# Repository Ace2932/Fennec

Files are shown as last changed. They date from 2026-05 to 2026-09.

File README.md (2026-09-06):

# Fennec — Autonomous Quadruped

> **Fennec** is an autonomous quadruped I'm building on the [NovaSM3](https://github.com/cguweb-com/Arduino-Projects/tree/main/Nova-SM3) platform (by Chris Locke / [novaspotmicro.com](https://novaspotmicro.com/)) — rebuilt around a unified Feetech STS3215 TTL servo bus, NVIDIA Jetson Orin Nano Super compute, and ROS 2 Humble, as a platform for Vision-Language-Action (VLA) model deployment, 3D SLAM, and autonomous mobile manipulation.

**Status:** 🔧 Phase 1 — hardware bring-up + sim training. **Both PCBs ordered 2026-07-01 (JLCPCB)** — power board v2 (Pattern B bus master, INA226 rail telemetry, Phase-4 arm rail provisioned) + logic board. Firmware critical-path green (safety FSM, watchdogs, servo limits, joint-map loader; rostest suites in CI). Legs (**leg_v6**) printing; chassis-integration + CAD fit-gate audits closed; measured leg geometry → URDF + IK green. **🎉 RL locomotion walks in sim** (MuJoCo MJX + Brax PPO, 2026-07-16) — stair-climb curriculum in progress. **See [`STATUS.md`](./STATUS.md) for the live blockers / next-actions board.**
**Platform:** Quadruped (12 DOF) — arm (6-DOF, Phase 4 future) on shelf
**Compute:** NVIDIA Jetson Orin Nano Super 8GB
**Middleware:** ROS 2 Humble
**Last updated:** July 22, 2026

---

> **Design outline:** [`docs/design-outline.md`](./docs/design-outline.md) — the canonical top-level design document (architecture, doctrines, lane status). Start there.

## Table of Contents

1. [Project Overview](#project-overview)
2. [Differences from Stock NovaSM3](#differences-from-stock-novasm3)
3. [Hardware Architecture](#hardware-architecture)
4. [Software Architecture](#software-architecture)
5. [Power System](#power-system)
6. [Network Topology](#network-topology)
7. [Bill of Materials](#bill-of-materials)
8. [Build Roadmap](#build-roadmap)
9. [Pre-Assembly Test Sequence](#pre-assembly-test-sequence)
10. [Setup Guide](#setup-guide)
11. [Open Decisions](#open-decisions)
12. [References & Credits](#references--credits)

---

## Project Overview

This project is a heavily modified fork of the open-source NovaSM3 quadruped, redesigned to serve as a research platform for embodied AI. Stock Nova uses PWM hobby servos and a Raspberry Pi running custom locomotion code. This build replaces:

- **12 servos** with Feetech STS3215 TTL bus servos for unified protocol, real-time joint feedback (position, load, temperature, voltage), and elimination of PWM wiring complexity. Six additional STS3215 (arm) remain on shelf for Phase 4.
- **The Pi** with an NVIDIA Jetson Orin Nano Super (67 TOPS sparse INT8 / ~33 TOPS dense; 8GB RAM tight but workable for VLA inference + ROS 2 + SLAM — see Phase 4 notes). Real-time servo bus is offloaded to a Teensy 4.1 (Pattern B); Jetson runs ROS 2 + perception only.
- **The stock perception** with Intel RealSense D456 (depth + RGB + IMU) and Unitree L2 4D LiDAR (360° × 96° FOV, 30m range)
- **The stock locomotion stack** with ROS 2 Humble (Jetson) + Teensy bus master (Pattern B) + Nav2 + RTAB-Map / POINT-LIO

The arm is carried over from a prior SO-ARM101 build, also Feetech-based. **v1 build scope: quadruped only (12 servos active).** Arm install + integration is Phase 4 future work — bus IDs 13-18 and the 7.5V arm-rail buck footprint (D42V55F7) are reserved on the PCB v6 redesign so the future install is a populate-and-go.

### Goals

- ✅ Unified TTL servo bus across locomotion (12 servos v1; future-ready for 18 with arm)
- 🔧 ROS 2 locomotion via micro-ROS bridge to Teensy 4.1 (Teensy owns the Feetech bus in Pattern B; FE-URT-1 retained as bench fallback)
- 🔧 RL locomotion policy trained in simulation (`sim/nova_mjx`, MuJoCo MJX + Brax PPO) — ✅ walks in sim (2026-07-16); terrain curriculum + stair climbing + sim2real transfer in progress
- 📋 3D SLAM using LiDAR + visual-inertial fusion (POINT-LIO baseline, RTAB-Map comparison)
- 📋 Autonomous navigation (Nav2) on legged platform with stair climbing
- 📋 VLA fine-tuning and deployment for mobile manipulation tasks
- 📋 Open-source documentation of every design decision for community reuse

---

## Differences from Stock NovaSM3

| Subsystem | Stock NovaSM3 | This Build |
|---|---|---|
| Compute (main) | Raspberry Pi 4 | NVIDIA Jetson Orin Nano Super 8GB |
| Compute (MCU) | Teensy 4.0 | Teensy 4.1 (more RAM + SD slot) |
| Aux MCU | Arduino Nano | Arduino Nano (kept, peripherals only) |
| Locomotion servos | 12× PWM hobby servos | 12× Feetech STS3215 (4× 12V/30kg hip, 8× 7.4V/19kg femur/tibia) |
| Arm | None (stock) | 6× Feetech STS3215 from SO-ARM101 — **on shelf, Phase 4** |
| Servo protocol | PWM (one signal per servo) | TTL half-duplex serial bus (daisy-chained) |
| Perception | None / optional | RealSense D456 + Unitree L2 LiDAR |
| Middleware | Custom Arduino loops | ROS 2 Humble + micro-ROS |
| Power | 3S 11.1V LiPo | 4S 14.8V LiPo + Pololu buck rails (7.5V leg / 12V hip / 12V L2 dedicated / 12V Jetson / 5V aux). XL4016 dropped after capacity audit. |
| Print materials | PLA / PETG | PA6-CF (structural) / PETG-CF (secondary) / TPU 95A (foot pads + strain relief) |
| Print feed | Direct from spool | **Creality SpacePi X4 dryer → 4 mm PTFE Bowden → P1S** (AMS HF bypassed for PA6-CF — re-absorbs moisture in AMS chamber, defeats pre-drying) |

### Why redesign the PCB (v5.2b → v6)

After the v3.2 architecture audit, the stock Nova PCB v5.2b can't host the upgraded power tree (Pololu modules, INA226 telemetry, hard-cutoff MOSFET, E-stop chain) or the Pattern A/B bus master selector. The redesign retains the spirit of the stock board (Arduino Nano aux slot, battery input geometry) and adds the new safety + power architecture. Full feature set in [`hardware/pcb-mods/README.md`](./hardware/pcb-mods/README.md).

### What carries over from Nova v5.2b

- Arduino Nano slot for aux peripherals — **v3.5 cut**: OLED + WS2812B only (PIR / ultrasonic / MP3 / MPU-6050 removed; D456 + L2 perception stack covers their roles)
- Battery input + reverse polarity protection geometry (replicated with MOSFET-based reverse protection instead of diode)
- Power switch, voltmeter, fuse (MRBF-30 in Blue Sea 5191 block, OFF-board at pack — ~9 kA AIC @ 16.8 V clears this pack's ~1.5–3 kA dead-short with 3–4× margin; ANL's 6 kA rejected, Class T superseded 2026-06-12)

### What changes

- All 12 PWM servo output headers removed (Feetech bus is daisy-chain TTL, doesn't use PWM)
- XL4016 buck footprints → Pololu D42V110-class module footprints
- Add: SN74LVC125A half-duplex driver (Pattern B prep), INA226 ×3, E-stop chain, hard-cutoff MOSFET, **MRBF-30 fuse OFF-board** (Blue Sea 5191 at pack — F1 not on PCB), bulk caps at injection points, bus-integrity footprints (series R + ferrite beads), reserved arm-rail buck footprint

---

## Hardware Architecture

### Block diagram

```
┌────────────────────────────────────────────────────────────────────┐
│                  NVIDIA Jetson Orin Nano Super 8GB                 │
│                          (ROS 2 Humble)                            │
│   • Nav2, SLAM, VLA inference, sensor fusion                       │
│   • Sends /joint_commands to Teensy via micro-ROS over USB         │
│   • Built-in WiFi 5 (802.11ac/ab/gn) per NVIDIA P3766 spec sheet   │
└──┬──────────┬─────────────┬─────────────┬───────────────────────────┘
   │ USB-C    │ USB 3.1     │ Ethernet    │ USB (micro-ROS transport)
   │          │             │             │
┌──▼───────┐ ┌▼───────────┐ ┌▼───────────┐ ┌▼─────────────────────────┐
│ Realsense│ │ FE-URT-1   │ │ Gig switch │ │ Teensy 4.1 (BUS MASTER v1)│
│ D456     │ │ (debug/    │ │            │ │  • Real-time gait loop    │
│ (depth + │ │  bench     │ │ ◄─ L2 ─►   │ │  • UART → SN74LVC125A → bus   │
│  RGB +   │ │  fallback) │ │            │ │  • INA226 I²C reader      │
│  IMU)    │ │            │ └────────────┘ │  • E-stop GPIO sense      │
└──────────┘ └────┬───────┘                │  • micro-ROS over USB     │
                  ↓                        └──┬────────────────────────┘
              (JP_BUS_MASTER                  │ UART → SN74LVC125A half-duplex
               solder bridge:                 │ (active v1 path)
               default = B,                   │
               flip to A for ID setup)        ▼
                                  ┌───────────────────────┐
                                  │ 12× STS3215 (TTL bus) │
                                  │ per-leg: FL1-3 FR4-6  │
                                  │ RL7-9 RR10-12 (h/f/t) │
                                  │  IDs 13-18: ⏸ arm    │
                                  │  (Phase 4 reserved)   │
                                  └───────────────────────┘

       ┌──── Arduino Nano (USB-serial bridge from Jetson:
       │                   OLED + WS2812B status LEDs) ────┐
       │                                                                  │
       └──────────────────────────────────────────────────────────────────┘
```

### Servo configuration

| Joint group | Count | Servo | Voltage | Bus IDs | Status |
|---|---|---|---|---|---|
| Hips | 4 | STS3215 30kg | 12V | 1-4 | v1 active |
| Femur + tibia | 8 | STS3215 19kg | 7.4V | 5-12 | v1 active |
| Arm (shoulder + elbow) | 3 | STS3215 19kg | 7.4V | 13-15 | ⏸ Phase 4 — reserved |
| Arm (wrist + gripper) | 3 | STS3215 19kg | 7.4V | 16-18 | ⏸ Phase 4 — reserved |

**v1 build = 12 active servos** on a single daisy-chained TTL bus, 2 active servo-power voltage levels (7.5V leg, 12V hip) plus dedicated 12V/2.6A L2 LiDAR buck and 12V/3A Jetson buck. Bus master is the **Teensy 4.1 (Pattern B)** via a SN74LVC125A half-duplex driver. Bus IDs 13-18 and the 7.4V arm rail (D42V55F7 footprint) reserved on PCB v6 for Phase 4 arm install — populate-and-go.

### Bus master pattern

**Pattern B is v1 default.** Both paths live on PCB v6 via solder bridge `JP_BUS_MASTER`.

- **Pattern B (v1 active):** Teensy 4.1 hardware UART → SN74LVC125A quad tri-state buffer (half-duplex driver) → TTL bus pads. Bare-metal real-time loop at 200-500 Hz. Jetson sends joint targets via micro-ROS over USB; Teensy translates to bus reads/writes. Survives Jetson restarts, kernel preemption, CUDA stalls, journald flushes — none of which affect bus servicing. Solder bridge defaults to B.
- **Pattern A (bench / debug fallback):** Jetson → USB → FE-URT-1 → TTL bus. Use for: initial servo ID assignment with the Feetech FD / SCServo SDK Python tools from a workstation (simpler than booting micro-ROS for ID setup), debug if Teensy firmware misbehaves, post-mortem inspection of bus traffic. Flip `JP_BUS_MASTER` to A.

**Why B as default (decision history):** Linux is not a real-time OS. USB-CDC latency on Jetson runs 1-10 ms typical, 50 ms+ under load. **What Pattern B actually buys:** bus-servicing isolation on the Teensy side — UART transactions to all 12 servos complete on time even when Jetson is jittery, so the bus doesn't time out and servos don't fault. The gait controller still runs on Jetson and publishes targets at 100 Hz, so Jetson's command rate is still Linux-bounded; the Teensy oversamples at 200-500 Hz against the last received target, holding it through Jetson stalls. A 100 ms Linux freeze becomes "robot pauses mid-step," not "bus dies and robot falls." v3.2 originally defaulted to A with "migrate if measurement forces it" — v3.3 flips to B-default because the migration cost is just populating one $1 IC + Phase 1 firmware work, and skipping the measure-then-migrate path eliminates a Phase 2 surprise. See Open Decisions row 5.

**Phase 1 acceptance gate (revised):** Pattern B's real guarantee is bus-servicing isolation on the Teensy side, not full RTT through Linux. Two mandatory criteria + one sanity check:
1. **Teensy local loop tick jitter p99 <100 µs** over 60 seconds (bare-metal — easy if firmware is right)
2. **`/joint_commands` arrival rate ≥99% of 100 Hz target** over 60 seconds (Jetson + uROS healthy)
3. *(Sanity)* End-to-end RTT median <5 ms, p99 <20 ms — Linux-bounded, not a hard pass/fail

If (1) misses → debug Teensy firmware (DMA vs ISR, UART config). If (2) misses → debug Jetson uROS / USB cable / CPU contention. If only (3) is high → accept: Teensy holds last command under Jetson jitter, robot stays stable.

---

## Software Architecture

### ROS 2 stack (target)

```
┌──────────────────────────────────────────────┐
│             Application Layer                │
│  • Behavior tree / mission FSM               │
│  • VLA policy node                           │
│  • Teleop bridge                             │
└──────────────────────────────────────────────┘
┌──────────────────────────────────────────────┐
│            Navigation Layer                  │
│  • Nav2 (planning + control)                 │
│  • robot_localization (EKF)                  │
└──────────────────────────────────────────────┘
┌──────────────────────────────────────────────┐
│              Perception Layer                │
│  • RTAB-Map / POINT-LIO (3D SLAM)            │
│  • realsense2_camera                         │
│  • unitree_lidar_ros2                        │
└──────────────────────────────────────────────┘
┌──────────────────────────────────────────────┐
│            Locomotion Layer (Jetson)         │
│  • Gait controller (8-phase walk)            │
│  • 3-DOF-per-leg IK solver                   │
│  • Publishes /joint_commands                 │
│  • Subscribes /joint_states                  │
└──────────────────────────────────────────────┘
┌──────────────────────────────────────────────┐
│        Bus Master Layer (Teensy 4.1)         │
│  • micro-ROS client (USB transport)          │
│  • SCServo SDK port — Feetech bus driver     │
│  • SN74LVC125A half-duplex TX/RX gating          │
│  • Real-time loop @ 200-500 Hz               │
│  • INA226 I²C reader → /diagnostics          │
└──────────────────────────────────────────────┘
┌──────────────────────────────────────────────┐
│              Hardware Layer                  │
│  • Feetech STS3215 bus (12 servos v1)        │
│  • IMU driver, aux peripheral I/O            │
└──────────────────────────────────────────────┘
```

### Key software components

| Component | Purpose | Status |
|---|---|---|
| ROS 2 Humble | Middleware | 📋 Install on Jetson |
| `librealsense2` | RealSense SDK | 📋 ARM64 build |
| `realsense2_camera` | ROS 2 wrapper for D456 | 📋 apt install |
| `unilidar_sdk2` | Unitree L2 SDK | ✅ Built green on Jetson (official `unitreerobotics/unilidar_sdk2`, **not discodyer fork** — official now bundles ROS 2 wrapper) |
| `unitree_lidar_ros2` | ROS 2 wrapper for L2 | ✅ Built + streaming. Use **Ace2932/unilidar_sdk2 `fix/imu-bridge-double-call` branch** — fixes upstream IMU bridge bug where `getImuData()` is called twice in `timer_callback()`, draining the SDK queue before publish. |
| POINT-LIO | LiDAR-inertial SLAM | 📋 Eval first |
| RTAB-Map | Visual-LiDAR SLAM | 📋 Compare with POINT-LIO |
| Nav2 | Autonomous navigation | 📋 Phase 3 |
| robot_localization | EKF sensor fusion | 📋 Phase 2 |
| micro-ROS (Teensy) | Embedded ROS 2 | 📋 Phase 2 |
| SCServo SDK (Teensy port) | Feetech bus driver running on Teensy in Pattern B | ⚠️ Already familiar from SO-ARM101 — port to TeensyDuino in Phase 1 |
| MJX/Brax sim (`sim/nova_mjx`) | RL locomotion training — MuJoCo MJX physics, Brax PPO, procedural terrain curriculum (rough / steps / stairs), domain randomization | 🔧 Walks in sim (flat trot, 2026-07-16); stair-climb curriculum active |

---

## Power System

### Voltage rails

```
4S LiPo 14.8V nominal (12.8-16.8V)
   │  MRBF-30 fuse (off-board) · MOSFET reverse-protection · MOSFET hard-cutoff @12.4V · E-stop NC (servo rails only)
   │
   ├── Pololu D42V110F7  ──► 7.5V/10A ──► 8× STS3215 19kg femur/tibia
   │       (star injection at 4 points along chain, bulk caps near point of load)
   │
   ├── Pololu D42V110F12 ──► 12V/9A   ──► 4× STS3215 30kg hips ONLY
   │
   ├── Pololu D24V22F12  ──► 12V/2.6A ──► Unitree L2 LiDAR (1A, LC filter on output)
   │
   ├── Pololu D42V55F12  ──► 12V/~3A  ──► Jetson Orin Nano (barrel jack)
   │
   ├── [reserved D42V55F7] ► 7.5V/3-8A ──► 6× STS3215 arm (Phase 4 — footprint unstuffed)
   │
   └── UBEC 5V/5A ──► 5V rail ──► fans, aux 5V peripherals

   INA226 ×3 (leg 7.5V, hip 12V, Jetson 12V) ──► I²C ──► Teensy 4.1 ──► ROS 2 diagnostics
   13.0V comparator ──► Teensy GPIO ──► /battery_low ──► Jetson clean shutdown
   12.4V comparator ──► MOSFET ──► breaks battery feed (autonomous backstop)
```

### Notes

- All rails share a common ground
- Jetson MAXN peak power ~25W → 2.1A at 12V, plus USB peripherals (D456 streaming ~2-3W, FE-URT-1 ~0.5W) → **~2.5A continuous worst case**. **Pololu D42V55F12** derates to ~3A continuous at 14.8V Vin (4.5A typ headline is at 42V Vin) → **~1.2× headroom**. Modest, not generous; watch thermal under sustained VLA inference + RealSense stream + Nav2 planning. Min Vin 12V — set LiPo LVC alarm at 3.3V/cell = 13.2V to stay above dropout.
- **Leg rail D42V110F7** (10A typ @ 42V Vin, derates at 14.8V Vin) sized for walking-gait avg 5-8A with bulk caps absorbing 25-40A impact transients near each star injection point. See [`docs/power-budget.md`](./docs/power-budget.md).
- **Hip rail D42V110F12** (9A typ @ 42V Vin) sized for 4× 30kg hips only — sustained avg ~8A. L2 LiDAR was moved off this rail to a dedicated D24V22F12 buck (v3.4) because combined hip+L2 load was margin-thin under 14.8V Vin derating.
- **L2 LiDAR rail D24V22F12** (2.6A / 12V / 36V Vin max) — dedicated buck for the LiDAR's 1A draw with LC filter on output. Clean power, no servo transient ringing.
- **Battery low-voltage chain** (ordered by trip point):
  1. **13.2V** — 608AC charger LVC alarm beeps (user-facing warning)
  2. **13.0V** — graceful-shutdown comparator → Teensy `/battery_low` topic → Jetson `systemctl poweroff` (clean SD unmount). ~30-60s window before hard cutoff.
  3. **12.4V** — autonomous MOSFET hard-cutoff on battery feed (drops everything; Jetson should already be shut down per #2)
- **E-stop** kills leg + hip + L2 rail enables (LiDAR stops spinning) — Jetson rail stays alive for post-mortem debug + telemetry capture.
- L2 self-heats below 30°C ambient; ~30-60s delay before point cloud output on cold boots
- LC filter sits on the D24V22F12 output to clean any switching ripple before the L2 input (UDP packet loss is the failure mode)

### Battery safety

- Always charge inside a LiPo safe bag
- Two 4S packs alternated; storage-charge to 3.8V/cell if unused >1 week
- Label packs (A/B) with first-use date; track cycle counts

---

## Network Topology

Point-to-point — no switch on the robot (decision 2026-08-14).

```
┌──────────────────────────┐               ┌────────────────────────┐
│ Unitree L2 LiDAR         │     Cat 6      │ Jetson Orin Nano       │
│ Static IP: 192.168.1.62  ├────────────────┤ eth0: 192.168.1.2/24   │
│ UDP target port: 6101    │    (direct)    │ wlan0: DHCP from home  │
└──────────────────────────┘                └────────────────────────┘
```

- L2 → UDP port 6101 on the Jetson, direct on `eth0`
- Jetson's `eth0` needs a manual static IP because L2 is not a DHCP client/server
- WiFi (built-in WiFi 5 / 802.11ac module on P3766 kit) handles dev SSH access + internet, leaving Ethernet free for the LiDAR. BT presence not explicitly listed in spec — verify on arrival.
- The 5-port switch is bench gear only — a dev laptop can join via the switch on the bench when wanted; it is not mounted on the robot.

---

## Bill of Materials

Full BOM lives in [`BOM.md`](./BOM.md). High-level summary:

| Category | Cost |
|---|---|
| Compute + perception | ~$1,300 (NVMe deferred — NAND shortage) |
| Servos | ~$320 active (12-servo v1) + 6 SO-ARM101 carryover on shelf |
| Power + safety | ~$338 (Pololu rails + INA226 + E-stop + MOSFET hard-cutoff + graceful-shutdown comparator) |
| Mechanical + hardware | ~$110 |
| Sensors (stock Nova) | ~$76 |
| Filament + Bambu accessories | ~$700 (− Magigoo via Bambu liquid glue substitution) |
| Wiring + consumables | ~$80 |
| **Realistic total** | **~$2,963** (v3.4: XT60 via Ovonic, Bambu glue, XL4016 ×2 return save $58 total) |

---

## Build Roadmap

**Superseded — this roadmap is the May-2026 plan kept for history. Live state: [`STATUS.md`](STATUS.md) (boards fabbed + populated to stage 9, firmware links, legs printing).**

### Phase 0 — Pre-build setup (current)

3-week sequenced plan in [`docs/work-schedule.md`](./docs/work-schedule.md). Front-loads leg-joint CAD + prints; reserves 2026-05-29 away-week for laptop-only PCB schematic work in KiCad.

- [x] Define modified BOM (v3.4: Pattern B default, Pololu 4-buck split incl. dedicated L2, full safety, arm deferred)
- [x] Validate component compatibility (Jetson power rail, Feetech bus, L2 ethernet)
- [x] Pick LiPo charger → **ISDT 608AC**
- [x] Power rail audit (XL4016 → Pololu D42V110-class)
- [x] Confirm v1 scope = quadruped only (arm → Phase 4)
- [x] Bus master decision → Pattern B (Teensy + 74HC125) v1 default
- [x] Set up GitHub repo with this README and BOM

**Week 1 (2026-05-15 → 2026-05-22):**
- [x] Leg CAD complete — V5 OpenSCAD original-shell-carve (`hardware/cad/leg_v5/`, STS3215 cavity in original NovaSM3 STLs). Pending: caliper on-hand servos + first-article leg-joint print.
- [ ] Install KiCad 8.x + Pololu library on laptop; cache datasheets for offline use during away-week
- [ ] Back up LeRobot Pi SD contents
- [ ] Create NVIDIA Developer account, download JetPack 6.x image

**Week 2 (2026-05-22 → 2026-05-28):** detailed checklist in [`docs/checklists/week-2.md`](./docs/checklists/week-2.md)
- [ ] Carryover from Week 1: caliper pass + first-article leg print (V5 leg CAD itself is done)
- [ ] ROS 2 Humble + librealsense2 + unilidar_sdk2 on Jetson (Jetson already flashed + persistent — Week 1 head-start)
- [ ] PlatformIO + TeensyDuino + micro-ROS Teensy firmware skeleton (compile-green)
- [ ] KiCad install + Pololu library (PCB v6 prep for Week 3)
- [ ] Bambu Studio + PA6-CF drier preheat

**Week 3 — Away (2026-05-29 → 2026-06-05, laptop only):**
- [x] PCB v6 **schematic** captured in KiCad 9 (2026-06-03) — §1-§8 hierarchical, all 54 parts footprinted, pin-name wiring audit passed, ERC-clean (1 intentional warning: reserved arm rail). See [`hardware/pcb-mods/README.md`](./hardware/pcb-mods/README.md)
- [ ] PCB v6 **layout** + DRC + Gerber export in KiCad
- [ ] Backup: continue Teensy firmware / URDF / ROS 2 scaffolding if PCB stalls or finishes early

**Week 4+ (back to shop):**
- [x] ~~Bench-validate prints; submit Gerbers to PCBWay (~$60)~~ — both boards fabbed at JLCPCB 2026-07-01 (~$203 all-in, see STATUS.md); continue Phase 1 hardware bring-up
- [ ] Order remaining parts (switch, Pololu bucks ×4, charger bundle, safety parts, accessories) — NVMe deferred

### Phase 1 — Hardware bring-up (weeks 1-4)

- [ ] Flash JetPack 6.x to microSD; firmware update Jetson if needed
- [ ] Boot Jetson, complete Ubuntu setup
- [ ] Verify pre-installed WiFi works; install AX210NGW only if missing. Confirm BT presence.
- [ ] Install ROS 2 Humble + librealsense2 + unilidar_sdk2 (run from 128GB microSD; NVMe deferred)
- [ ] D456 standalone test (`realsense-viewer`)
- [ ] L2 standalone test (included 12V adapter + rviz2)
- [ ] Print parts: Bambu P1S + PA6-CF (dry 24h before each print)
- [ ] Bench-validate Pololu D42V55F12 / D42V110F7 / D42V110F12 / D24V22F12 / UBEC 5V (per BOM §12 step 2)
- [ ] Verify E-stop chain + MOSFET hard-cutoff @ 12.4V + INA226 I²C reads
- [ ] **Write Teensy firmware** (Pattern B critical path) — micro-ROS client + SCServo SDK port + SN74LVC125A TX/RX gating
- [ ] ID setup pass: flip `JP_BUS_MASTER` to A (FE-URT-1), assign servo IDs **1-12** (v1 active), label each. IDs 13-18 reserved for Phase 4.
- [ ] Flip `JP_BUS_MASTER` back to B (default). Verify Teensy firmware drives single servo, then full 12-servo chain.
- [ ] **Acceptance gate** (two mandatory + one sanity, see "Bus master pattern" section): Teensy tick jitter p99 <100 µs + `/joint_commands` arrival ≥99% of 100 Hz + RTT median <5 ms / p99 <20 ms. Pattern A is not a workaround if (1) or (2) miss.
- [ ] Assemble legs (redesigned for STS3215 dimensions)
- [ ] Assemble chassis, mount L2 on top-center riser
- [ ] Network setup: eth0 static 192.168.1.2; verify L2 UDP flow
- [ ] Arduino Nano: strip code to aux peripherals only
- [ ] Stand / sit test on hardware (no walk yet)

### Phase 2 — Locomotion (weeks 5-8)

> Two parallel tracks: the classical IK/gait stack below, and an **RL policy trained in
> simulation** (`sim/nova_mjx` — MuJoCo MJX + Brax PPO, procedural terrain curriculum,
> domain randomization bracketing measured servo behavior). The RL track walks in sim as
> of 2026-07-16; its deployment path is ONNX/TFLite-class policy export to the Jetson.

- [ ] Implement 3-DOF-per-leg IK solver (reference mogar/spot_micro)
- [ ] 8-phase walk gait controller on Jetson — publishes `/joint_commands` to Teensy via micro-ROS
- [ ] Stand, sit, walk validated on hardware
- [ ] Body stabilization feedback via D456 IMU (MPU-6050 cut per BOM v3.5)
- [ ] Calibrate LiDAR ↔ RealSense extrinsics
- [ ] EKF fusion: D456 IMU + L2 IMU via `robot_localization` (MPU-6050 cut)
- [ ] RTAB-Map 3D SLAM on walking platform
- [ ] POINT-LIO comparison (LiDAR-IMU only)

### Phase 3 — Autonomy (weeks 9-12)

- [ ] Nav2 integration on legged platform
- [ ] Costmaps from D456 + L2
- [ ] Autonomous waypoint navigation
- [ ] Obstacle avoidance during walk
- [ ] Stair climbing test (gait variation)
- [ ] Telemetry dashboard

### Forward-looking backlog (opportunistic, not scheduled)

Quality-of-life software + operational features captured in [`docs/notes-qol-features.md`](./docs/notes-qol-features.md) and [`docs/notes-virtual-view-autocal.md`](./docs/notes-virtual-view-autocal.md). Pick up during Phase 1/2 idle time or batch into a "QoL sprint" once v1 walk gait is stable. Suggested rollout order (per `notes-qol-features.md`):

1. **Preflight health check** (`nova_ops`) — bus ping sweep, E-stop, battery latch. v1 ships 3 checks; rest land opportunistically. Highest payback during Phase 1 servo bring-up.
2. **`make deploy` for Teensy** — build on laptop, flash over Jetson USB, no chassis open. Needed by mid-Phase-1 firmware iteration.
3. **Always-on MCAP dashcam** with incident freeze on E-stop / fault / manual trigger. Required before first walk attempt.
4. **`nova bringup` launcher with profiles** (`bench` / `sensors` / `slam` / `walk` / `full` / `vla`) — pay back at ~6 launch files.
5. **Per-joint safety envelope** in the gait controller — position/velocity/load/temp clamping. Paired with first Phase 2 gait controller commit.
6. **Battery SoC widget** — gated on adding a 4th INA226 on battery feed (PCB v6 footprint already supports it).
7. **RGB status LED** on Arduino Nano — Phase 2 polish.
8. **Telemetry CSV writer** → optional Grafana later (resist Docker on Jetson).
9. **Bag replay harness** — Phase 3 when SLAM/Nav iteration is the bottleneck.
10. **Gazebo Fortress digital twin** — Phase 4 prep for VLA dev without HIL.

Plus auto-calibration routines (`nova_calibration` package): IMU bias zero on boot, servo zero-position auto-detect via jig, camera↔IMU + LiDAR↔IMU + LiDAR↔camera extrinsics. Foxglove bridge over Tailscale for remote browser viewing of URDF + sensors + plots.

### Phase 4 — Arm install + Manipulation + VLA (future, after Phase 3 stable)

Split into two sub-phases since hardware-arm-install precedes any manipulation software.

**Phase 4a — Arm hardware install:**
- [ ] Populate D42V55F7 arm-rail buck on PCB v6
- [ ] Install 6× STS3215 arm servos (carried from SO-ARM101), assign bus IDs 13-18
- [ ] Mechanical mount of arm to chassis (CAD pending)
- [ ] Full 18-servo daisy-chain ping test
- [ ] Bench-validate arm rail under realistic load

**Phase 4b — Manipulation + VLA software:**
- [ ] Arm joint state integration into unified URDF
- [ ] MoveIt 2 motion planning for arm
- [ ] **COM-shift compensation** in gait controller (arm extension + payload mass shifts support polygon — gait controller needs arm-state input)
- [ ] VLA model selection (OpenVLA / Pi0 / RT-2 class). Constraint: 8 GB RAM shared with ROS 2 + SLAM + RealSense full rate. OpenVLA INT4 fits but tight; budget memory carefully.
- [ ] Data collection harness for in-house fine-tuning
- [ ] On-device VLA inference (TensorRT-optimized)
- [ ] Mobile manipulation demo: navigate to object, grasp, transport

---

## Pre-Assembly Test Sequence

Before assembling any subsystem into the chassis, validate on the bench. Catching a bad part on the desk is minutes; catching it after assembly is hours.

1. **Jetson desk bring-up** — Firmware update → JetPack flash → Ubuntu setup → SDK installs → individual sensor smoke tests (NVMe migration deferred — see BOM §1)
2. **Power rail validation** — Each buck/converter loaded with realistic current draw before being committed to the chassis
3. **Servo bring-up** — Single-servo bench tests before daisy-chaining; full chain ping before powered movement
4. **Network smoke test** — Static IPs, L2 UDP packet flow, simultaneous SSH-over-WiFi
5. **Sensor smoke test** — OLED + WS2812B via Arduino Nano USB-serial (PIR/ultrasonic/MPU/DFPlayer cut per BOM v3.5)

Full test sequence and acceptance criteria in [`BOM.md`](./BOM.md) Section 12.

---

## Setup Guide

> 📋 To be written as components arrive. Will include:
> - JetPack 6.x flash + firmware update procedure
> - NVMe rootfs migration (when NAND prices recover; see BOM §1)
> - Built-in WiFi 5 setup + BT verification
> - ROS 2 Humble + sensor SDK install scripts
> - Feetech servo ID assignment procedure
> - Network static IP configuration
> - URDF + xacro for the modified platform
> - Calibration procedures (servo zero-positioning, sensor extrinsics)

---

## Open Decisions

| # | Decision | Status | Notes |
|---|---|---|---|
| 1 | Charger model | Resolved → ISDT 608AC | ~$60. AC mode ~55W ≈ 110 min for 4S 6000mAh. Charge / discharge / **storage** modes. Bag + XT60 jumper bought separately. |
| 2 | WiFi on P3766 kit | Resolved → 802.11ac/ab/gn included | Confirmed from NVIDIA P3766 datasheet (Developer Kit Content): "802.11ac/ab/gn wireless network interface controller". WiFi 5, **not** 6E. Antennas implied via product photos; verify-on-unbox. |
| 2b | Bluetooth presence on P3766 | **Resolved → BT 5.1 confirmed (Realtek)** | Verified 2026-05-17 on hardware: `hciconfig -a` shows `hci0` UP RUNNING, Manufacturer "Realtek Semiconductor Corporation", HCI Version 5.1, BD Address 9C:C7:D3:F6:AC:5C. `bluetoothctl list` confirms controller present. |
| 3 | L2 12V tap: shared with hip rail vs dedicated buck | **Resolved → dedicated D24V22F12** (v3.4) | Combined hip+L2 load was margin-thin on D42V110F12's 9A typ at 14.8V Vin derating. Split L2 to its own buck for $19 extra. Cleaner power, more hip-rail headroom. |
| 4 | SLAM stack: POINT-LIO vs RTAB-Map | Open | Compare during Phase 2 |
| 5 | Bus master: Pattern A (FE-URT-1) vs Pattern B (Teensy) | **Resolved → B is v1 default** | Linux jitter (USB-CDC 1-10 ms typical, 50 ms+ under load) is unacceptable at 100 Hz gait. Teensy bare-metal UART gives hard real-time. PCB v6 keeps Pattern A via `JP_BUS_MASTER` bridge for bench / ID setup / debug. Phase 1 acceptance gate (revised): Teensy loop p99 **<100 µs** + `/joint_commands` arrival ≥99% of 100 Hz + RTT sanity (median <5 ms, p99 <20 ms). |
| 6 | L2 mounting position | Resolved → top-center on riser | Symmetric 360° FOV, minimal yaw moment |
| 7 | Horn spline verification | Resolved → absorbed into leg redesign | |
| 8 | NVMe SSD purchase | Deferred → NAND shortage | May-2026 NAND flash shortage 2-3x'd 1TB SSD prices ($60→$165-220). Revisit when prices recover (<~$100 for 1TB) or storage becomes a measured bottleneck. Run from 128GB microSD until then. |
| 9 | v1 scope: arm included vs deferred | Resolved → arm deferred to Phase 4 | 12 active servos (4 hip + 8 femur/tibia). 6 arm servos on shelf. Bus IDs 13-18 + arm-rail buck footprint reserved on PCB v6. |
| 10 | Power rail strategy | Resolved → 4-buck Pololu split | XL4016 8A cont. inadequate. v3.4 active rails: D42V110F7 (leg 7.5V), D42V110F12 (hip 12V only), D24V22F12 (L2 12V dedicated), D42V55F12 (Jetson 12V). Arm rail D42V55F7 footprint reserved. See [`docs/power-budget.md`](./docs/power-budget.md). |
| 11 | Safety scope | Resolved → full | 608AC LVC alarm at 13.2V (warning) + 13.0V graceful-shutdown comparator → Jetson clean poweroff + 12.4V MOSFET hard-cutoff (autonomous backstop) + E-stop on leg/hip/L2 rail enables + INA226 ×3 per-rail telemetry. ~$37 BOM add. |
| 12 | Phase 4 COM-shift compensation | Open (Phase 4) | Arm extension + payload mass shifts support polygon; gait controller needs arm-state input to stay stable. Design when arm install begins. |
| 13 | Bus integrity strategy at 12 nodes / 1 Mbps | Open (measure first) | PCB v6 includes footprints for series R + ferrite beads + GND-plane reference (GND plane = single low-Z return). Single-ended TTL — **not** RS-485, so 120 Ω differential termination is not the right tool. Populate iteratively based on measured error rate; drop baud if needed. |

---

## References & Credits

- **Original NovaSM3** by Chris Locke (cguweb) — [GitHub](https://github.com/cguweb-com/Arduino-Projects/tree/main/Nova-SM3) · [novaspotmicro.com](https://novaspotmicro.com/) · [Discord](https://discord.gg/bJWgTMccUx) — base platform, chassis geometry, parts list. PCB v5.2/v5.3 reference via [PCBWay community share](https://www.pcbway.com/project/shareproject/NovaSM3_v5_2.html). Note: repo ships STL only, **no STEP** (re-model from STLs + datasheet + calipers for OnShape).
- **mogar/spot_micro** — ROS 2 reference for quadruped IK and gait
- **discodyer/unitree_lidar_ros2** — ROS 2 wrapper for Unitree L2
- **Feetech SCServo SDK** — TTL bus driver
- **NVIDIA Jetson AI Lab** — JetPack documentation, VLA model deployment guides
- **POINT-LIO** — Unitree-recommended LiDAR-inertial SLAM
- **Nova Discord community** — Build gotchas, assembly tips

---

## Project Status Log

| Date | Milestone |
|---|---|
| 2026-05-15 | BOM v3 finalized, README v1 created |
| 2026-05-15 | BOM v3.1 — NVMe deferred (NAND shortage), charger resolved to ISDT 608AC, WiFi confirmed included |
| 2026-05-15 | D24V50F12 → D42V55F12 buck swap (older Pololu family deprecated) |
| 2026-05-15 | BOM v3.2 — v1 scope narrowed to quadruped only; arm to Phase 4. Power rails redesigned (XL4016 → Pololu D42V110-class). Full safety scope adopted (LVC + E-stop + INA226 + MOSFET hard-cutoff). PCB v5.2b → v6 redesign. |
| 2026-05-15 | BOM v3.3 — Bus master flipped: **Pattern B (Teensy + 74HC125) is v1 default**. Pattern A (FE-URT-1) kept as bench / debug fallback via solder bridge. Teensy firmware becomes Phase 1 critical path. |
| 2026-05-15 | 3-week work schedule committed ([`docs/work-schedule.md`](./docs/work-schedule.md)): leg-joint CAD on OnShape now, prints week 2, PCB v6 schematic in KiCad during 2026-05-29 away-week. |
| 2026-05-16 | BOM v3.4 — L2 LiDAR split off hip rail onto dedicated D24V22F12 buck after Pololu datasheet check showed D42V110F12's 9A typ @ 42V Vin derates below combined hip+L2 ~9A load at 14.8V Vin. +$19. |
| 2026-05-16 | Two-pass internal audit: Pass 1 swept 7.4V/7.5V mismatches + stale version markers + stale L2 references + section numbering; Pass 2 reframed Phase 1 acceptance gate (Teensy tick jitter + uROS arrival rate, not RTT), clarified Pattern B benefit framing, extended E-stop to kill L2 rail too, added 13.0V graceful-shutdown comparator before 12.4V hard cutoff, noted pre-PCB ID-setup path, reconciled Jetson headroom (~1.2× incl. peripherals). +$3 safety, total ~$3,015. |
| 2026-05-16 | Order status updates: ISDT 608AC + LiPo safe bag + Mxuteuk HB2-ES544 E-stop ordered. Ovonic 4S kit confirmed to include XT60 jumper + charging lead (−$13). Bambu Lab Liquid Glue substituted for Magigoo PA (−$15, with print-test gate to fallback if PA6-CF adhesion fails). Realistic total $3,015 → $2,993. |
| 2026-05-16 | LeRobot Pi SD backed up to `~/Backups/lerobot-pi-128gb-2026-05-16.img.gz` (SHA256 recorded in [`docs/backups.md`](./docs/backups.md)). Card reformatted for Jetson. |
| 2026-05-17 | Jetson Orin Nano Super: flashed JetPack 6.2.1 SD image → apt full-upgrade → **JetPack 6.2.2 / L4T 36.5 running**. MAXN_SUPER power mode set (mode 2 on this Dev Kit, not 0). Three first-boot networking gotchas hit + documented in [`docs/setup-network.md`](./docs/setup-network.md): (1) oem-config WPA association fails — skip + connect from CLI; (2) l4tbr0 USB-C bridge hijacks default route — unplug or lower WiFi metric; (3) NetworkManager doesn't write `/etc/resolv.conf` on this image — manually populate + `chattr +i` to lock immutable. |
| 2026-05-17 | **Open decision 2b resolved:** Bluetooth confirmed present on P3766 — Realtek, BT 5.1, `hci0` up. |
| 2026-05-17 | Jetson **full persistence verified across reboots**: JetPack 6.2.2, MAXN_SUPER (mode 2), `jetson_clocks.service` (systemd oneshot), DNS chattr-immutable, WiFi profile, BT. 8-point verification block lives in [`docs/setup-jetson.md`](./docs/setup-jetson.md) §11. |
| 2026-05-17 | **Week 1 substantially closed** — Jetson bring-up overtook the planned CAD-first sequence (no harm). CAD + KiCad + Teensy firmware skeleton carried to Week 2. New checklist at [`docs/checklists/week-2.md`](./docs/checklists/week-2.md). |
| 2026-05-17 | **ROS 2 Humble installed on Jetson via ros2-apt-source 1.2.0 deb (deb822 format, the new canonical method).** `ros-humble-desktop` + `python3-colcon-common-extensions` + `python3-rosdep` running. Talker/listener verified working over DDS. |
| 2026-05-17 | **Background research pass committed.** `docs/research/2026-05-17-notes.md` consolidates 14 topics: Unitree L2 SDK (use official, drop discodyer fork), POINT-LIO ROS 2 fork (dfloreaa), librealsense2 via jetsonhacks prebuilt modules, STS3215 libraries for Teensy, 74HC125 wiring, INA226 + LM393 design, MAXN_SUPER clocks verified (1.7 GHz / 1020 MHz), OpenVLA feasibility on 8GB. **Two safety/correctness fixes applied:** (a) **ANL → Class T 30A fuse** (LiPo needs 20 kA AIC, ANL only 6 kA), (b) **NovaSM3 repo URL corrected** to `cguweb-com/Arduino-Projects/Nova-SM3` (the old `SovGVD/NovaSM3` returns 404). |
| 2026-05-17 | **Unitree L2 stack built green on Jetson.** Cloned `unitreerobotics/unilidar_sdk2`, built C++ SDK + `unitree_lidar_ros2` ROS 2 wrapper. `colcon build` clean. Confirmed launch params + topics: `/unilidar/cloud` (cloud_scan_num: 18), `/unilidar/imu`, default IPs match BOM §5 (LiDAR 192.168.1.62, target 192.168.1.2 port 6101). Topic/frame mapping captured in [`docs/setup-network.md`](./docs/setup-network.md) for POINT-LIO + URDF integration. |
| 2026-05-17 | Network bundle ordered: gigabit 5-port unmanaged switch (TP-Link LS105G / NETGEAR GS305) + Cable Matters 10 Gbps snagless Cat 6 × 2-3 (1ft). $23 spend. Will unblock L2 standalone test via `ros2 launch unitree_lidar_ros2 launch.py` once delivered (~2 days). |
| 2026-05-18 | **XL4016 ×2 returned for $30 refund.** Originally specced in v3.0 BOM as the servo-rail buck pair. v3.2 audit caught the 8A continuous limit being inadequate for walking-gait + impact transients on either the 7.5V leg rail or the 12V hip rail — replaced with Pololu D42V110-class modules. XL4016 was kept in spares bin until now; return path cleaner. Realistic total $2,993 → $2,963. |
| 2026-05-18 | **Intel RealSense D456 full stack (Color + Depth + IMU) running on Jetson.** Step A: `librealsense2-utils` + `librealsense2-dev` via Intel apt repo (key FB0B24895113F120 fetched from keyserver.ubuntu.com). Step B: stock JetPack 6.2.2 kernel modules don't expose IMU — patched 3 in-tree drivers (uvc, IIO accel, IIO gyro) via `jetson-orin-librealsense` + rebuilt against L4T 36.5 sources via `jetson-orin-kernel-builder`, enabled `HID_SENSOR_HUB/ACCEL_3D/GYRO_3D` modules, ~25 min compile. Step C: `ros-humble-realsense2-camera` launched. Verified: Color 30 Hz, Depth 30 Hz, Accel 101 Hz, Gyro 200 Hz on actual hardware. Full procedure captured in [`docs/setup-jetson.md`](./docs/setup-jetson.md) §13. |
| 2026-05-18 | **Unitree L2 LiDAR streaming end-to-end.** Wired L2 ↔ Cat 6 ↔ gigabit switch ↔ Cat 6 ↔ Jetson `enP8p1s0` (192.168.1.2/24 static via `nmcli connection nova-lan`). Ping to L2 (192.168.1.62) at 0.1 ms. `ros2 launch unitree_lidar_ros2 launch.py` brings up `/unilidar/cloud` at **12 Hz, 5042 points/scan, frame_id `unilidar_lidar`**. Followup: `/unilidar/imu` topic advertised but no UDP frames arriving — driver `initialize_type` config may need tuning (non-blocking since D456 IMU at 200 Hz covers EKF). **Full v1 perception stack online:** RGB + depth + 2 IMUs + 3D LiDAR all in ROS 2. |
| 2026-05-19 | **POINT-LIO ROS 2 (dfloreaa fork) built green on Jetson** in 1:42 colcon. Phase 2 SLAM toolchain compile-ready. L2-specific config at `unilidar_l2.yaml` (scan_line 18, imu_time_inte 0.004 = 250 Hz). Runtime tests deferred until L2 IMU ROS bridge bug fixed OR `imu_en: false` LiDAR-only mode set. |
| 2026-05-19 | **Teensy 4.1 PlatformIO firmware skeleton compile-green on Mac** in 9.58 s (Flash 12.8 KB / 8 MB free; RAM1 487 KB / RAM2 512 KB free). Pin map + 74HC125 OE GPIO scaffolding + INA226 I²C placeholder + safety GPIO sense + 1 Hz LED heartbeat + USB-CDC log lines. micro-ROS lib_deps gated behind `NOVA_USE_MICRO_ROS` — Mac build path breaks on Python 3.14 + missing ROS dev libs; reinstate on Jetson for runtime testing. Repo path: `firmware/teensy/firmware/`. |
| 2026-05-19 | **Teensy firmware end-to-end on Jetson.** IntervalTimer ISR-driven 200 Hz tick → loop p99 = **1 µs** (50× under <100 µs acceptance gate). micro-ROS over USB-CDC + 20-topic contract live. `feetech::Bus` driver code-complete (untested on wire). |
| 2026-05-20 | **Firmware safety + telemetry batch:** safety FSM (E-stop + battery-low latch + `/safety_clear`), full STS3215 telemetry (pos+vel+load + voltage + temp @ 5 Hz), per-joint slew limiter on SYNC_WRITE broadcast, software watchdog (ISR-checked main-loop progress + AIRCR reset), boot-time servo ping sweep → first real `/servo_present_mask`, INA226 → `/power_rails` Float32MultiArray @ 10 Hz, `/firmware_version` + boot self-test for safety GPIOs, categorised bus errors (`/servo_err_timeout` + `/servo_err_bad_frame` + `/servo_err_servo`). CI green on every PR. |
| 2026-05-21 | Threadlocker (Loctite 243) + tape ordered. DP adapter dropped (headless SSH path validated). |
| 2026-05-23 | **L2 IMU bridge fixed** via Ace2932/unilidar_sdk2 fork — `/unilidar/imu` now publishes @ 250 Hz, POINT-LIO green end-to-end (init walks 1% → 100% within 250 ms). Per-room PCD capture procedure documented in `setup-jetson.md` §15. |
| 2026-05-23 | **AMS HF bypassed for PA6-CF print workflow** — feed direct from Creality SpacePi X4 → 4 mm PTFE Bowden → P1S. PA6-CF re-absorbs ambient moisture in AMS chamber within hours, defeating the 24 h pre-dry. SpacePi X4 keeps filament heated through the entire print. |
| 2026-05-23 | **Magigoo PA reinstated** in BOM. Bambu Lab liquid glue is not rated for PA / PA-CF per their product page; Bambu wiki PA6-CF guide explicitly calls for PA-specific glue stick. The −$15 substitution was a false economy vs the cost of a 10 h first-layer detachment. |
| 2026-05-24 | **Forward-looking feature notes committed** (PR #1, merge `8cb8b1e`): [`docs/notes-qol-features.md`](./docs/notes-qol-features.md) (preflight check, always-on MCAP dashcam with incident freeze, per-joint safety envelope, `nova bringup` launcher with profiles, `make deploy` for Teensy, bag replay harness, telemetry → CSV/Grafana, RGB status LED, battery SoC widget, Gazebo digital twin) and [`docs/notes-virtual-view-autocal.md`](./docs/notes-virtual-view-autocal.md) (Foxglove bridge over Tailscale, IMU bias zero on boot, servo zero-position auto-detect, camera/LiDAR/IMU extrinsic auto-cal). Notes only — opportunistic pickup during Phase 1/2 idle time. New packages proposed: `nova_ops` + `nova_calibration`. |
| 2026-05-26 | **Leg CAD done — V5 OpenSCAD original-shell-carve** ([`hardware/cad/leg_v5/`](./hardware/cad/leg_v5/README.md)). Reuses the original NovaSM3 STLs and carves an STS3215 cavity inside via boolean `difference()` — keeps the original shape, resizes the servo pocket. 9 STLs (shoulder + coax_L/R + femur_shell_L/R + femur_cover_L/R + tibia_L/R); femur prints as shell+cover sharing one cavity; tibia passive. Beat the from-scratch OnShape (V4) + CadQuery (V3.1) brackets → those archived. Pending: first-article print (coax X-bbox tight). |
| 2026-05-30 | **CAD docs reorganized:** V2/V3/V4 leg attempts moved to `hardware/cad/archive/`; `hardware/cad/README.md` + `docs/cad-tooling.md` reframed to the three-track model (V5 OpenSCAD = leg links, CadQuery = utility, OnShape = chassis). |
| 2026-06 | Cross-domain **system audit** (firmware / PCB / software / docs alignment) opened; PCB v6 split into power + logic boards, layout + DRC iterations. Leg CAD moved to **leg_v6** (Onshape, STS3215-exact reference frame, load-path + fit-gate doctrine). |
| 2026-07-01 | **Both PCBs ordered via JLCPCB** (~$203 all-in): power board v2 (Pattern B bus master, 74HC125 driver, INA226 rail telemetry, Phase-4 arm rail provisioned) + logic board. v7 backlog captured. |
| 2026-07-06 | **System audit fully closed:** servo firmware-limits lane, limp mode, watchdogs, joint-map loader. rostest suites (firmware limits, watchdog, joint-map, liveness, locomotion) wired into CI. |
| 2026-07-10 | **leg_v6 caliper session:** 25T horn disc-to-disc measured 35.5 mm, yoke fixed, servo insertion proven; battery mount redesigned (top-flange); chassis-integration audit closed. Measured femur 106.9 / tibia 129.0 mm → URDF + IK green. |
| 2026-07-13 | **CAD fit-gate audit closed:** every leg + chassis screw joint gated on both sides (bolted-joint gate pattern — probe STL first, solid-ring guard, blind-pocket proof, negative control). Legs printing. |
| 2026-07-16 | 🎉 **First walk — in simulation.** RL policy (MuJoCo MJX + Brax PPO, proprioceptive obs) trots on flat ground in `sim/nova_mjx`. Curriculum + DR bracket measured servo behavior (2.8 rad/s joint cap, ~75 ms latency). |
| 2026-07-20 | **Terrain-relative reward rework** (#129/#130): resume-safe curriculum accounting; collision-exact terrain height under each foot — done/height/contact all terrain-relative, flat behavior bit-identical. |
| 2026-07-21 | **Climb objective** (#131) + unidirectional staircases: privileged-heightmap teacher policy, signed non-farmable ascent reward. Project renamed **Fennec**. Stair-climb bootstrap iteration continues (climb-v2: PBRS approach density + joint pad curriculum). |
| TBD | Phase 0 → Phase 1 transition (parts in hand) |
| TBD | First successful walk gait — on hardware |

---

*This is a learning project as much as a research one. Decisions and tradeoffs are documented openly so others can fork and adapt.*

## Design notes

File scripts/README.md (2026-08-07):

# Scripts

Bring-up + maintenance helpers.

## Setup

`proj/.venv/bin/pip install -r scripts/requirements.txt` (pyserial, PyYAML —
see that file for why each is here).

## Files
- `flash-jetpack.sh` — JetPack 6.x microSD flash helper (stub)
- `set-servo-ids.py` — Feetech STS3215 bus-ID assignment via FE-URT-1.
  Protocol (checksum/frame/parse) is tested against mocks + the C++
  reference (`firmware/teensy/firmware/src/feetech_protocol.h`) in
  `test_set_servo_ids.py` — run with `.venv/bin/python -m pytest
  scripts/test_set_servo_ids.py`. Still bench-unproven: no real STS3215 has
  talked to it over an actual FE-URT-1 yet. Walkthrough in
  `docs/setup-servos.md`.

Each script is a stub until the corresponding hardware step has been
walked through manually at least once. Codifying happens after the
procedure works by hand — not before.

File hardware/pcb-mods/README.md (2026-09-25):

# NovaSM3 PCB v6 — Design Spec

Custom PCB replacing the upstream NovaSM3 v5.2b. Driven by the v3.2 architecture audit:
- XL4016 buck rails undersized for walking-gait current (8A cont. vs measured 8-12A avg + 25-40A impact transients)
- No safety chain (no LVC, no E-stop, no per-rail telemetry, no fuse spec)
- No Pattern B prep (any future Teensy-owns-bus migration requires chassis teardown)
- Stock PWM servo headers unused (Feetech bus is daisy-chain TTL)

Reference: BOM v3.2 §2, §3 · [`docs/power-budget.md`](../../docs/power-budget.md) · README "Power System" section.

---

## Feature set (v6 must-have)

### 1. Battery input + reverse protection

- XT60 panel-mount input (matches Ovonic packs)
- **MOSFET-based reverse-polarity protection** (not a diode — too much Vdrop at 10-15A continuous)
- **MRBF-30 terminal fuse — OFF-BOARD**, Blue Sea 5191 block at the pack in the battery→PCB lead (not a PCB footprint; F1 removed from `nova_pcb_v6` 2026-06-04). 30A time-delay, sized for hip-rail worst case ~20A + headroom. ANL/MIDI's ~6 kA interrupt rating can "fail to interrupt" a LiPo dead-short (vapor reconducts) → rejected. Class T (20 kA) was the interim spec, but this single 4S pack's real Isc ≈ 16.8 V ÷ 6–12 mΩ ≈ **1.5–3 kA**, vs MRBF's **~9 kA AIC @ 16.8 V = 3–4× margin** at ⅓ the size/weight → **MRBF chosen 2026-06-12**. At-source placement also protects the battery→PCB cable. See [`docs/research/2026-05-17-notes.md`](../../docs/research/2026-05-17-notes.md) §9 + [`docs/order-list.md`](../../docs/order-list.md) MRBF section.
- Power switch (off-board Blue Sea Contura SPST, **~18A @ 16.8 V DC**; 20A@12V / 15A@24V) wiring to on-board SW1 block. Sized for ~14A sustained; the SW1 terminal block matches it (15–20A class). The 30A MRBF is catastrophic-short (kA) protection, **not** the switch-path thermal limit — so SW1 block + switch are intentionally rated below the fuse.
- Mini digital voltmeter retained for at-a-glance pack state

### 2. Four active power rails + one reserved (v3.4 split)

| Rail | Module | Output | Sized for | Status |
|---|---|---|---|---|
| Leg | Pololu D42V110F7 | 7.5V / 10A typ @ 42V Vin | 8× STS3215 19kg | Active v1 |
| Hip | Pololu D42V110F12 | 12V / 9A typ @ 42V Vin | 4× STS3215 30kg ONLY | Active v1 |
| L2 LiDAR | Pololu D24V22F12 | 12V / 2.6A | Unitree L2 (1A, dedicated buck for clean power) | Active v1 (added v3.4) |
| Jetson | Pololu D42V55F12 | 12V / ~3A cont. | Jetson Orin Nano Super MAXN | Active v1 |
| Arm | Pololu D42V55F7 | 7.5V / 3-8A | 6× STS3215 arm (Phase 4) | **Footprint reserved — DO NOT populate v1** |
| Aux 5V | UBEC 5V/5A (off-board) | 5V / 5A | Fans, aux peripherals | Header on board |

Module footprints use Pololu's standard header pitch so cards can be swapped without PCB respin. L2 split from hip rail (v3.4) because D42V110F12's 9A typ @ 42V Vin derates to ~7-8A at our 14.8V Vin, and combined hip+L2 sustained ~9A was over budget.

**Buck modules are OFF-BOARD (2026-06-05).** All five Pololu cards mount in a 3D-printed finned holder (open-air cooling), NOT soldered to the PCB. Forcing reason: every Pololu module is 100 % THT, so on-board the two PCB faces are **not independent placement planes** — pins pierce both. The 5 bucks alone are 47 % of the 112×90 board on a single plane, which pushes the all-THT board to ~74-84 % packing (hand-solder ceiling ≈55 %): it does not fit and is not hand-solderable. Off-board frees ~half the board and cools the bucks better than sandwiching them in the 20 mm mezzanine gap. The PCB keeps the buck **wire-terminal landings** at U1-U5 (footprint swap module → terminal, **netlist untouched** — same move as the INA226 swap). The finned holder is a CAD task tracked separately.

### 3. Servo bus distribution (star injection)

- Single signal bus (daisy-chained TTL) — no break
- **4 power injection points** along the leg 7.5V trunk (one per leg pair)
- **Bulk caps (1000 µF / 25V) at each injection point** — soaks impact transients near point of load
- GND-plane reference (FE-URT-1; solid GND plane = single low-Z return)
- Hip rail injects at chassis floor (4 hips clustered there)

### 4. Bus master — Pattern B default, Pattern A fallback

**Pattern B is the v1 active path.** Teensy 4.1 hardware UART routed through **SN74LVC125A quad tri-state buffer** as a half-duplex driver to the Feetech TTL bus pads. The SN74LVC125A must be populated on first build.

- Teensy UART TX → SN74LVC125A input gate
- Teensy GPIO → SN74LVC125A OE pins (TX-enable for write, RX-enable for read; half-duplex direction control)
- SN74LVC125A output → bus signal pad
- FE-URT-1 USB→TTL input header retained for fallback

Solder bridge `JP_BUS_MASTER` selects which path drives the bus pads:

- **B (default — board ships configured this way):** Teensy UART → SN74LVC125A → bus
- **A (fallback):** FE-URT-1 → bus directly (used for ID setup, debug, post-mortem)

Both paths terminate on the same bus pads; the bridge is the only state change. No chassis teardown to swap.

Linux jitter rationale: USB-CDC latency on Jetson is 1-10 ms typical, 50 ms+ under CUDA / kworker / journald load. Pattern B isolates the bus-servicing side (Teensy completes UART transactions to all 12 servos on time even when Jetson stalls); the gait command rate from Jetson is still Linux-bounded but the Teensy holds-last-command at 200-500 Hz, so a 100 ms Jetson freeze becomes a mid-step pause instead of a bus timeout.

### 5. Bus integrity footprints (populate per measured error rate)

Feetech bus is **single-ended half-duplex TTL UART**, not RS-485. 120 Ω differential termination is the wrong tool here.

- Series R footprints (22-100 Ω, 0603) at FE-URT-1 / SN74LVC125A output — slope rate-limiting
- Ferrite bead footprints at each servo entry — common-mode noise rejection
- GND-plane reference (FE-URT-1; solid GND plane = single low-Z return)

Default v1 build: leave footprints unpopulated. Populate iteratively if bus error rate exceeds threshold during bring-up. If still poor, drop baud 1M → 500k → 250k.

### 6. Safety chain

Three-stage battery low-voltage chain (highest trip first):
- **Charger LVC alarm:** ISDT 608AC set to **3.3V/cell = 13.2V** (warning beep, user-facing)
- **Graceful-shutdown comparator:** **3.25V/cell = 13.0V** pack. Comparator (LM393) + resistor divider → Teensy GPIO input. Teensy debounces + publishes `/battery_low`. Jetson subscribes + runs `systemctl poweroff` to unmount SD cleanly. ~30-60 s window before the hard cutoff trip at typical discharge rates — enough for Jetson to halt.
- **MOSFET hard-cutoff:** **3.1V/cell = 12.4V** pack. Second comparator stage drives a logic-level MOSFET on the battery feed. Autonomous backstop — fires whether or not Jetson shut down per the 13.0V trigger.

Other safety:
- **E-stop:** panel-mount latching button, NC contact. Wired in series with the **leg + hip + L2 rail enable lines** (D42V110F7 + D42V110F12 + D24V22F12 EN pins). Killing L2 stops the LiDAR spinning under emergency. Jetson rail stays alive for post-mortem debug + telemetry capture. Twist-to-release.
- **INA226 ×4:** one per active rail (leg 7.5V @0x40, hip 12V @0x41, Jetson 12V @0x44, L2 12V @0x45 — the L2 monitor is U12, populated, not optional since 2026-06-30). I²C bus to Teensy 4.1 → ROS 2 diagnostics topic. Per-rail current/voltage telemetry. **All four are identical 2 mΩ-shunt breakout modules** (Adafruit INA226 / "20A" generic) on 2.54 mm THT headers — the module's onboard shunt closes the high-side sense loop, so there is **no bare VSSOP-10 chip and no external 2512 shunt** (was the v1 plan for leg/hip; standardized to modules 2026-06-04). Must be a **2 mΩ** board: cheap 0.1 Ω "meter" modules saturate above ~0.8 A (useless on 8-12 A rails). Net effect: the board now has **zero fine-pitch parts** — everything is THT or 1.27 mm SOIC / SOT-23.

### 7. Aux MCU + peripherals (carryover from Nova v5.2b)

- Arduino Nano slot (3-pack already owned). **BOM v3.5 cut: only SSD1331 OLED + WS2812B LEDs remain active.** PIR / ultrasonic / DFPlayer / MPU-6050 dropped (redundant with D456 + L2 perception stack). Nano now acts as USB-serial bridge from Jetson driving the OLED (SPI) + LED strip (1 GPIO).
- Teensy 4.1 footprint (already owned) for INA226 I²C reader, E-stop GPIO, Pattern B half-duplex driver

### 8. Mechanical / connector convention

- M3 mounting holes matching chassis (TBD from CAD)
- JST-XH 2.54 for low-current signals
- XT30 for servo power injection trunks
- XT60 panel-mount for battery
- All connectors keyed to prevent reverse insertion

---

## Mezzanine stack — cross-board coordinate contract

The 2-board stack is **face-to-face vertical**, NOT an edge-mate. Logic board on TOP (component side UP — Teensy 4.1 + USB face the removable riser deck, so the deck lifts off for service without unstacking the boards), power board on BOTTOM (component side UP), joined by inter-board connector **J20** (2×6 IDC + ribbon) and **4 corner M3 standoffs** (20 mm) — note this is the UPPER set only; a second set of 4 at the same length and pattern carries the power board off the floor plate below it, so the build needs **8** (corrected 2026-08-18). ~~Stack ≈41 mm tall, fits the ~46.9 mm chassis trunk depth.~~ **Wrong comparison:** the real ceiling is `STACK_TOP_Z ≈ 62.22` (Teensy/Nano socket top, measured off the parsed board mesh) and the trunk plateau is 46.91. The stack does not fit inside the trunk and never had to — it rises into the riser bay, clearing the deck underside (67.9) by 5.68 mm. All user I/O (both USB, OLED cable, LED cable, FE-URT bus) exits the **front (low-Y) edge**.

**Both boards share ONE absolute KiCad coordinate frame.** Holes + J20 only mate if their XY match across boards. Logic board is mounted component-side-up by **flipping about the vertical centerline x=140** — so everything in the contract is symmetric about x=140 and survives that flip.

### Locked values (logic board `nova_pcb_v6_logic`, floorplan DONE)

| Item | Value | Note |
|---|---|---|
| Outline (Edge.Cuts) | `(98,57)-(182,135)` = **84×78 mm** | center **(140,96)** = trunk middle |
| Standoff H1-H4 (M3) | `(103,63) (177,63) (103,129) (177,129)` | ±37 from x=140, symmetric → flip-invariant |
| J20 interboard | `(140,124)` **rot90** (6-pin axis along X) | on x=140 axis → stays put under flip; ribbon absorbs pin-1 mirror |

### Power board (`nova_pcb_v6_power` #67) MUST match

- **Same absolute origin frame** (do not re-zero).
- **Same 4 standoff XY**: `(103,63) (177,63) (103,129) (177,129)`.
- **J20 at `(140,124) rot90`** (short ribbon reach to logic J20; ribbon handles pin-1).
- **Outline ENCLOSES logic**, centered (140,96): target ~**112×90 mm** → `(84,51)-(196,141)`.
- Power-board I/O (XT60 battery, XT30 injection, E-stop, switch) goes on the **rear/side edges**, clear of the logic board's front-edge I/O column.
- **Bucks U1-U5 are off-board** (finned holder) — the board carries only their wire-terminal landings, not the 32×44 mm module bodies. On-board THT that remains (INA ×3 + bulk caps + ring/injection connectors + L1 + switches) ≈ 37 % of one plane → 2-sided placement is now genuinely viable.

---

## Out of scope for v6

- Wireless: keep on Jetson (built-in WiFi 5)
- Storage: Jetson NVMe is direct M.2 (not on PCB)
- High-current arm rail: footprint reserved but unpopulated (Phase 4)
- Custom switching designs (TPS54824 etc.): Pololu modules used instead — easier debug, faster spin, no SMPS expertise needed

---

## Design workflow

1. Schematic in KiCad (or Eagle). Reference designators consistent with BOM v3.4.
2. Footprint placement: keep servo connectors on chassis-facing edge, Jetson connectors on top edge.
3. Power planes: separate 4-layer stackup (top sig, GND, PWR, bottom sig). GND-plane reference (FE-URT-1).
4. DRC + ERC clean before Gerber export.
5. PCBWay order: 5 boards (spares + iteration), 2 oz copper, ENIG finish, stencil for SMD.
6. First-article: hand-populate one board, bench-test every rail before populating others.

---

## Length matching (#416)

A length-matching **rule and gate exist now** so the first board where mismatch is
actually an electrical problem (see "Carry to LPL HIVE" below) already has the
tooling. On the two active v6 boards today it is **not fixing anything** — no
copper changed for this ticket — it is establishing the budget and the CI gate
before they're needed.

**Budget formula:** skew ≈ Δlength × ~6.8 ps/mm (FR-4 typical propagation
delay). A group's `tolerance_mm` is chosen well under the electrical bound
that formula gives (5% of the signal's bit period, converted to a length via
that formula) — see each `length_match.json`'s `budget` string for the exact
derivation per group. On these boards that electrical bound is 3-4 orders of
magnitude looser than the routed lengths (a few thousand mm vs a few tens of
mm), so `tolerance_mm` is set as a **layout-discipline bound** instead — a
number close enough to the measured spread on main to still catch a gross
miroute (a leg rerouted the long way around, a net that grew 10x), not to
enforce timing margin that doesn't apply at these speeds.

**Measured** (recomputed directly from the `.kicad_pcb` `(segment)`/`(via)`
records by `tools/check_length_match.py`, 2026-09-25 — see that command's own
output for the authoritative numbers; the issue's hand-measured table agreed
within its own stated 0.1 mm tolerance except the via count, corrected below):

`nova_pcb_v6_logic` — 155 segments, **4 vias** (the issue's "8 vias" counted
`(vias allowed)` net-class lines, not `(via ...)` records — corrected here):

| group | net | length | vias |
|---|---|---|---|
| Feetech bus (1 Mbaud half-duplex TTL, Pattern B) | `TEENSY_TX` | 55.65 mm | 0 |
| | `TEENSY_RX` | 54.31 mm | 1 |
| | `OE_TX` / `OE_RX` | 52.55 / 52.06 mm | 0 |
| | `BUS_SIGNAL` / `BUS_SERVO` | 40.84 / 40.63 mm | 0 |
| OLED SPI (Teensy/Nano → series-R `_F` nets → SSD1331) | `SPI_SCK`+`SPI_SCK_F` | 52.97+7.27 = 60.24 mm | 0 |
| | `SPI_MOSI`+`SPI_MOSI_F` | 29.82+11.55 = 41.37 mm | 0 |
| | `OLED_CS`+`OLED_CS_F` | 50.88+3.71 = 54.60 mm | 1 |
| | `OLED_DC`+`OLED_DC_F` | 33.56+8.93 = 42.49 mm | 0 |
| I²C (INA226, 400 kHz) | `I2C_SCL` / `I2C_SDA` | 46.44 / 46.44 mm | 0 |

`nova_pcb_v6_power_v2`: `I2C_SDA` 196.16 mm (3 vias) vs `I2C_SCL` 162.76 mm (1
via); `BUS_SERVO` 62.46 mm (2 vias, informational only — a single net has no
partner to match against).

**Gate:** `tools/check_length_match.py <board.kicad_pcb> <length_match.json>`
— stdlib-only (no `pcbnew` import), so it runs in CI and on the Mac. Sums
routed copper length per net from the board file, adds a per-via allowance
(`via_allowance_mm` in the spec — derived from the board's own `(general
(thickness …))`, since one through via traverses the full stackup), and
checks each group's spread against `tolerance_mm` and each member against the
optional `max_mm`. Nets are matched to the spec by **leaf name** — the part
of the KiCad net name after the last `/` — because several nets here carry a
hierarchical sheet prefix that itself contains `/` and even `+`
(`/07 Aux MCU + Peripherals/SPI_SCK`), so a spec net list is a JSON array of
leaf names, never a `+`-joined string.

Exit codes: `0` pass, `1` a group's spread exceeds `tolerance_mm` or a member
exceeds `max_mm`, `2` a net named in the spec is missing from the board or
present but unrouted (0 length, 0 vias) — checked *before* 1, so a spec typo
or a deleted net can never be graded as a silent pass. `--selftest` runs a
synthetic two-net fixture through all four outcomes (pass, spread-fail,
missing-net, unrouted-net) with no real board file needed.

CI: `.github/workflows/cad-gates.yml`'s `pcb-length-match` job runs
`--selftest` plus both real boards on every PR that touches the checker, a
board's spec, or the two `.kicad_pcb` files. `tools/test_check_length_match.py`
is the pytest regression suite (run in `ros-pytest.yml`, next to
`test_fab_gate.py` — that file is a standalone script, not
pytest-collectible, see its own docstring).

**In-editor feedback (best effort):** `nova_pcb_v6_logic.kicad_dru` adds
`(constraint length (max …))` rules matching the same `max_mm` ceilings, so
KiCad's own DRC flags a wildly-over-length net while routing. **This is not
the source of truth and cannot fully express the rule above:** KiCad's
`skew` constraint only evaluates true differential pairs, and none of these
groups are diff pairs (the Feetech bus is single-ended TTL, not RS-485 — see
the bus README). There is no KiCad 9/10 DRC construct that checks *group
spread* across independent single-ended nets, so the `.kicad_dru` rules are
per-net `max` ceilings only — they cannot catch "net A grew 20 mm relative to
net B while both stayed under max", which is exactly what
`check_length_match.py` checks and CI enforces. Verified by tightening one
rule to an obviously-violated bound and confirming `kicad-cli pcb drc` reports
it (`length_out_of_range`); at the real thresholds committed here it adds
**zero** new DRC violations (17 pre-existing `lib_footprint_mismatch` before
and after — unrelated cosmetic findings, not touched by this ticket).

**Adding a net to a group:** append its leaf name to the relevant
`length_match.json` `members` list (a new list entry for a standalone net, or
appended into an existing member's array to sum it with its `_F`/continuation
net). Re-run the gate once — it will report the new spread — and only then
decide whether `tolerance_mm` still holds or needs its own re-derivation
(update the `budget` string, never just the number).

**Carry to LPL HIVE:** same tool, different numbers, once a HIVE repo exists
to hold them (none was reachable under `Ace2932` as of 2026-09-25). The groups
that will actually need tight matching there: Ethernet MDI pairs (intra-pair
≤ ~0.1 mm, inter-pair ≤ ~5 mm — real diff-pair matching, where KiCad's `skew`
constraint DOES apply, unlike everything on the v6 boards), RMII
(`REF_CLK` vs `TXD`/`RXD` within the PHY's setup/hold), SDMMC/eMMC
(`CLK` vs `DAT0-3`/`DAT7`), QSPI flash, and the SAR ADC `SCLK`/`SDO` group.
The checker is repo- and board-agnostic by construction (a `.kicad_pcb` path
+ a JSON spec) on the assumption HIVE is KiCad; only the parser would need to
change for Altium.

---

## Open questions for design phase

- Final D42V55F7 footprint orientation on arm-rail reservation (depends on Phase 4 mechanical install)
- Whether to integrate the lighted rocker switch into the PCB or keep panel-mount via flying lead
- Whether to add a USB-C dev port for direct Teensy programming (vs pulling the Teensy out for USB-A flashing)
- Whether to mirror the v5.2b voltmeter on the PCB or panel-mount

Resolve during schematic review.

---

> ⚠️ **DEPRECATED (2026-06-05):** the single-board `nova_pcb_v6/` is **superseded by the 2-board mezzanine** — `nova_pcb_v6_power/` (battery / rails / servo-bus / safety) + `nova_pcb_v6_logic/` (Teensy / 74HC125 / Nano), joined by inter-board connector **J20**. New work happens on the mezzanine projects; this single board is kept for reference/history only. **Teensy/Nano power-input fix was NOT back-ported here:** in this capture the Teensy 4.1 is fed via its 3.3V *output* pin with VIN floating (cannot back-power a Teensy 4.x — onboard PMIC needs VIN) and the Nano `+5V`/`VIN` both float — corrected **only on the mezzanine logic board** (`V5_AUX` → Teensy VIN + Nano `+5V`). The bug remains in this single-board project and will not be fixed.
>
> **Status:** design spec at BOM v3.5 / v0.3.2-l2-dedicated. **Schematic captured + board placed** in KiCad 9 (`nova_pcb_v6/`, §1-§8 hierarchical, autobuild). Schematic: all 51 components footprinted (was 54 — F1 Class-T fuse + R13/R14 2512 shunts removed 2026-06-04) — KiCad-stock libs except **9 components on 5 custom footprints** in `nova_v6.pretty/` (3 Pololu buck families D24V22/D42V55/D42V110 on U1–U5, Teensy 4.1 socketed 2×24 on U6, INA226 breakout module on U9/U10/U11; geometry reconstructed from Pololu dim PDFs + PJRC card11a + INA226 module outline, every `descr` flagged **VERIFY vs physical part before fab**). **Buck connector pin orders extracted + corrected from the Pololu dimension drawings** (reg19a / reg34a / reg34c) + board photos: D42V55 **un-mirrored** to VOUT·GND·VIN·VRP·PG·EN (the prior footprint had it reversed — would have driven the module's VIN pin into an NC/VRP hole), D24V22 set to PG·EN·VIN·GND·VOUT, D42V110 power column re-spanned to 17.94 mm with the invented SCL/SDA/ENB/PFM signal names removed (the family carries only VOUT/GND/VIN/VRP/EN/PG); verified board sizes + per-buck pin maps recorded in [`../../hardware/cad/dimensions.md`](../../hardware/cad/dimensions.md) §4. Net-bearing pad sets (1/2/3/4) unchanged, so the netlist is untouched — propagate the corrected pad geometry to placed U1-U5 via pcbnew **Tools → Update Footprints from Library** (preserves hand-placement). Pin-name-level wiring audit passed, ERC clean except 1 intentional warning (`V7V5_ARM` — reserved Phase-4 arm rail, DNP); audit added the two missing off-board load connectors J12 (`V12_JET`→Jetson) + J13 (`V12_L2`→L2 LiDAR). Power-monitor topology standardized (2026-06-04): all three rails — U9 leg / U10 hip / U11 Jetson — use the identical INA226 breakout module whose onboard 2 mΩ shunt closes the high-side sense loop; external 2512 shunts R13/R14 deleted (each module's internal shunt now bridges that rail's RAW↔clean nets, exactly as the Jetson rail already did). ERC re-run clean (0 errors, 1 expected `V7V5_ARM` warning). L2 12V rail gains a 22 µH + cap LC filter (L1) for LiDAR-clean power. **Layout placement complete:** all 54 footprints placed by power flow (battery left edge → 5 Pololu bucks → INA226 sense → bulk caps → right-edge injection connectors; logic/safety in bottom band; M3 holes at corners), 0 overlaps, spacing audited for Pinecil V2 hand-soldering (≥3.6 mm body gap on the radial caps). Solder load: ~34 parts, all easy THT/SMD — with all 3 INA226 now THT breakout modules the board has **zero VSSOP-10 drag-solder parts** (prior fine-pitch concern eliminated), and the off-board fuse drops F1 from the board; 13 DNP tuning/fallback footprints (R1, R2-R12, FB1) left unpopulated. Netclasses set. **Board re-sync pending (2026-06-04 schematic changes):** the placed `.kicad_pcb` still holds the pre-change 54 footprints — open pcbnew → **Tools → Update PCB from Schematic (F8)** to apply: delete F1 + R13 + R14, and swap U9/U10 from `VSSOP-10` to `nova_v6:INA226_Module_Breakout` (F8 preserves hand-placement of the other footprints; the two bigger INA modules land at U9/U10's old spots and may need a small nudge). **Pending CAD board dims:** Edge.Cuts outline + M3 hole pattern. Next: copper routing + GND / high-current pours (thermal-relief spokes on THT pads so the Pinecil can melt joints) → DRC → Gerber export.
> **Owner:** Aiden Fox.

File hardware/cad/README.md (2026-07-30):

# CAD

> Top-level design: [`docs/design-outline.md`](../../docs/design-outline.md)

Three tracks, deliberately split. **Full setup guide:** [`docs/cad-tooling.md`](../../docs/cad-tooling.md).

**Python deps for the gates:** [`requirements.txt`](./requirements.txt) (#200) —

```bash
proj/.venv/bin/pip install -r hardware/cad/requirements.txt
```

That file is the *single* source: `cad-gates.yml` (all four jobs) and
`ros-pytest.yml` both install from it. They used to carry hand-written lists,
which drifted — `ros-pytest` was missing `mujoco` and `trimesh`, so 11
CAD↔URDF↔MJCF guards **skipped** in CI while passing locally, green either way
(#213). Add a dep there, not in a workflow. Note `embreex` is effectively
required: without it trimesh silently drops to a pure-numpy ray engine and the
fit sweep needs ~5 GB instead of ~3 GB (#178/#197).

- **OpenSCAD functional legs — `leg_v6/`** — **CANONICAL leg design** (coax, femur + bolt-on knee arm, tibia, straps). Ground-up designed-for-assembly parts around the real STS3215 mesh: drop-in pockets, both-discs-bolted joints, cable management, vents, side dots; every build runs the real-mesh fit gate + pose-sweep collision checks (`leg_v6/check_fit.py`). See [`leg_v6/README.md`](./leg_v6/README.md). `leg_v5/` (shell-carve) + `leg_v5_screwlock/` are SUPERSEDED — kept for the shape-preserving carve technique and the stock-STL provenance; V2-V4 in [`archive/`](./archive/README.md).
- **OnShape via [Jarvis OnShape MCP](https://github.com/ReshefElisha/jarvis-onshape-mcp)** (Claude Code plugin, ~60 tools + FeatureScript) — **chassis + multi-body kinematic assemblies**, anything with mate relationships, anything that imports reference STEPs (Jetson, L2, D456). Source of truth for the chassis/structural stack. (It lost the leg-link competition to V5 — original geometry mattered more than from-scratch brackets.)
- **parametric-3d-printing skill** (`~/.claude/skills/parametric-3d-printing/`, CadQuery-based) — utility parts: cable guides, sensor adapters, mount brackets, panel cutouts, foot pads, strain reliefs, PCB carriers, riser towers, connector pockets, print-test coupons. Anything single-body or single-assembly.

Project-specific macros live in [`hardware/cad/patterns.md`](./patterns.md) (version-controlled with this repo). Project-scoped skill at `.claude/skills/nova-sm3-cad/SKILL.md` auto-loads when working in this project — wraps the patterns file + delegates CadQuery code generation + STL export to the upstream `parametric-3d-printing` skill. Covers Bambu P1S + PA6-CF tolerances, STS3215 dual-shaft mount, LiPo pocket, XT60 / XT30 / E-stop / RJ-45 / USB / barrel cutouts, RealSense D456 + L2 LiDAR riser + Teensy + Arduino Nano + INA226 mounts, Pololu buck carriers + LC filter pocket, P3766 antenna mount, WS2812B status LED, leg-rail star injection, TPU foot pads + strain reliefs, servo zero-position calibration jig. Read it before generating new utility parts.

## Will contain (in this directory)

- OnShape public doc URL (once created)
- Exported `*.step` + `*.stl` for assemblies
- Print orientation notes per part (fiber alignment for PA6-CF)
- `measurements.md` — caliper-measured servo + horn + bearing dims

## Reference geometry sources

- **STS3215** (19kg + 30kg variants) — pull STEP from GrabCAD or Feetech site, import to OnShape
- **NovaSM3 reference chassis** — `cguweb-com/Arduino-Projects/tree/main/Nova-SM3` (the `SovGVD/NovaSM3` URL in old docs was a misattribution; that repo does not exist). **STEP files NOT in repo — only STL.** For OnShape import: (a) import STL as static body, (b) re-model from STL + datasheet + caliper, or (c) contact Chris Locke for original Fusion source. See [`docs/research/2026-05-17-notes.md`](../../docs/research/2026-05-17-notes.md) §8.
- **Feetech 25T servo horns** — datasheet dims, model in OnShape from scratch
- **688ZZ ball bearings** (8 × 16 × 5 mm) — **RETIRED 2026-07-10** — leg_v6 uses the servo's integral idler wheel, not external bearings (vestigial from leg_v5); generic deep-groove, no STEP needed; press-fit pocket geometry is in [`patterns.md`](./patterns.md) §3
- **Calipers** for in-hand cross-check — STS3215 body tolerance is ±0.1 mm batch-to-batch, never trust a single datasheet number for press-fit work

## Print workflow

1. OnShape (kinematic) or CadQuery skill (utility) — design + export STL
2. Slice in Bambu Studio with PA6-CF profile (280 °C nozzle, hardened steel hotend, 100 % infill on structural)
3. **Filament feed:** Creality SpacePi X4 → 4 mm PTFE Bowden tube → P1S top-side input. **AMS HF bypassed** for PA6-CF — re-absorbs moisture in AMS chamber within hours, defeats the 24 h pre-dry. PA6-CF stays in the heated dryer chamber for the entire print.
4. Bed prep: Bambu **Engineering Plate** (smooth) + **Magigoo PA glue stick** (Bambu liquid glue is not rated for PA / PA-CF — see BOM §8 note). 100 °C bed soak 15 min before first layer.
5. First-article gate on every structural part — print one, caliper, fit-test on real STS3215, then batch. Skip the batch if fit isn't clean.

## Files in this directory

- [`leg_v6/`](./leg_v6/) — canonical leg design (OpenSCAD designed-for-assembly sources + STLs). Start at [`leg_v6/README.md`](./leg_v6/README.md).
- [`leg_v5/`](./leg_v5/) — SUPERSEDED shell-carve leg design, kept for the shape-preserving carve technique + stock-STL provenance. Not for new leg work.
- [`dimensions.md`](./dimensions.md) — canonical part dims (✅ verified / ⚠️ review / ❌ missing). Wins on any conflict.
- [`patterns.md`](./patterns.md) — CadQuery macros for project utility parts.
- [`parametric-servo-fit.md`](./parametric-servo-fit.md) — PA6-CF press-fit clearance calibration (V5 pulls `CLR_BODY` from here). The OnShape-Variable-Studio parametric workflow it describes is superseded by V5's literal clearance.
- [`archive/`](./archive/README.md) — superseded leg designs V2/V3/V4 + the V4 OnShape build plan.
- Chassis OnShape exports (`*.step` / `*.stl`) will land here once the chassis doc is built.
- Sibling project folders (outside `proj/`): `~/codebases/NOVA/original_body_files/` (Chris Locke source STLs that V5 imports), `~/codebases/NOVA/feetech_servo_models/` (STS3215 STEP), `~/codebases/NOVA/Unitree_LiDAR/`

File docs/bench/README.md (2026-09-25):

# Servo bench captures — STS3215 (7.4V 19kg variant, ID 1)

Bench: Waveshare Bus Servo Adapter (A), USB-C data + external DC on DC+/DC−.
Supply: Kungber, **7.5 V** / 3 A limit (matches robot D42V110F7 leg rail).
Logger: `scripts/bench_step_response.py` (raw Feetech, ~2500 Hz sample).

## Config registers (as-shipped)
P/D/I gain = 32 / 32 / 0 · accel = 0 (unltd) · goal_speed = 0 (unltd)
max_torque = 1000 · angle limits 0..4095. Sim `kp=35` ≈ measured P=32 — good.

## No-load step response @ 7.5 V (s1_step{30,60,90}_noload.csv)
| step | latency (cmd→motion) | settle (2%) | peak speed (raw) | peak load (raw) |
|---|---|---|---|---|
| 30°  | 80 ms | 0.49 s | 1250 | 1388 |
| 60°  | 76 ms | 0.69 s | 1800 | 1548 |
| 90°  | 75 ms | 0.84 s | 2200 | 1668 |

- ~75 ms command→motion **deadtime is real** (static friction + deadband) — same
  at 5.3 V and 7.5 V, so not undervoltage. Feed this into the sim latency buffer.
- No overshoot — internal loop is well-damped / rate-governed, not springy.
- No-load motion is voltage-insensitive; load headroom is where voltage matters.

CSV cols: `t_s, cmd_cnt, pos_cnt, speed_raw, load_raw`. 4096 cnt/rev.

⚠ **Load columns above and below are mis-decoded (corrected 2026-09-25).** The logger
read load with bit 15 as the sign; the STS3215 uses **bit 10** (Feetech SDK
`ReadLoad`, #422), and the register is the **motor PWM duty in 0.1 %**, not torque
(Feetech memory table 0x3C: "voltage duty cycle"). No sample has bits 11-15 set.
Re-decoded, the no-load peaks are **364 / 524 / 644** (36-64 % duty while moving with
no external load). New captures log `load_duty_permille`, decoded correctly.
Loaded captures (torque-speed) = TODO at bench.

## Loaded step @ 7.5 V — 201 g at 57.1 mm lever (~0.11 N·m horizontal)
s1_step{up60,dn60}_load201_r57.csv · static hold: ~~load_raw ≈ 1048 @ 0.11 N·m~~ →
**1048 = direction bit (1024) + 24**; re-decoded hold is 32-40, i.e. **3-4 % duty**
at ~6 % of stall torque (gearbox friction carries the rest). Corrected 2026-09-25.

| run | settle | peak speed (raw) | peak load (raw) |
|-----|---|---|---|
| no-load 60° | 0.69 s | 1800 | 1548 |
| +60° lifting  | 0.69 s | 1800 | 1600 |
| −60° dropping | 0.69 s | 1800 |  500 |

- Speed UNCHANGED under 0.11 N·m (~6% stall) → in normal regime the servo is
  ~~**speed-governed / rate-limited**~~ **acceleration-limited** (corrected
  2026-09-25: peak speed rises with step size, 1.92 / 2.76 / 3.37 rad/s for
  30 / 60 / 90°, while v²/θ stays 7.0-7.3 rad/s². That is the servo's internal
  trajectory profile, ~7-9 rad/s² even at accel = 0; see #428), not torque-limited. Model it as a
  rate-limited position tracker in the sim (NOT a spring); torque-speed droop
  only near stall (~1.9 N·m ≈ 3.4 kg at this lever — not captured).
- Load register senses direction (lift 1600 vs drop 500); ~~static hold anchors
  raw→N·m (~1048 raw @ 0.11 N·m)~~ the register is duty, not torque, so there is
  no raw→N·m anchor here (corrected 2026-09-25, see the warning above).

## Sine tracking @ 7.5 V, no load (#428 check 4, measured 2026-09-25)
Leg servo (7.4 V part, the #462 control unit), horn free, ±15° about 2048, goals
streamed at 100 Hz (the firmware command rate), ~2400 samples/s.
`bench_step_response.py --sine-hz ...` · CSVs `leg_sine15_<hz>hz.csv`.

| Hz | amplitude ratio | lag | accel ceiling est. | peak duty |
|---:|---:|---:|---:|---:|
| 0.5 | 0.99 | 80 ms | tracking | 17 % |
| 1.0 | 1.01 | 237 ms | tracking | 38 % |
| **1.4** | **0.53** | 331 ms | 8.35 rad/s² | 37 % |
| **2.0** | **0.27** | 261 ms | 8.80 rad/s² | 26 % |
| 3.0 | 0.13 | 192 ms | 9.78 rad/s² | 22 % |

GOAL_ACC at 2 Hz (`leg_sine15_acc{0,50,254}_2hz.csv`): ratio 0.26 / 0.27 / 0.27,
ceiling 8.59 / 8.61 / 8.73 rad/s². **The register does not lift the ceiling** (true only while reg 85 = 50: once reg 85 is raised, a nonzero GOAL_ACC IS the limit; see below).

- **Position mode cannot pass a 1.4-2 Hz gait swing**: half the amplitude at
  1.4 Hz, a quarter at 2 Hz. It matches the sim's profile model (~0.45), not a
  plain position servo (~0.87).
- **It is not power**: peak duty stays at 17-38 %. The servo's own trajectory
  generator (~8.5 rad/s²) is the limit, so `NOVA_GOAL_ACC 50` and a torque
  limit of 600 change nothing here, unloaded.
- ~~Not tested: EEPROM reg 85 and MODE 2~~ → tested the same day, below.

### The ceiling is a register: reg 85 Maximum_Acceleration (measured 2026-09-25)
As-shipped reads: reg 85 = **50** (not in the Feetech memory table; LeRobot names it
`Maximum_Acceleration` and writes 254), reg 86 = 1, lock 0x37 = 1. 50 × 100 steps/s² =
5000 steps/s² = 7.7 rad/s²: that IS the ceiling above. All writes below were made with
the lock at 1 (lost at power cycle) and restored to the as-shipped values after.

| config | 1.4 Hz ratio / lag | 2 Hz ratio / lag | 3 Hz ratio / lag | ceiling est. |
|---|---|---|---|---|
| reg 85 = 50 (factory) | 0.53 / 331 ms | 0.27 / 261 ms | 0.13 / 192 ms | 8.4-9.8 rad/s² |
| **reg 85 = 254**, acc 0 or 254 | **0.97 / 60 ms** | **0.99 / 75 ms** | 0.55 / 173 ms | **40 rad/s²** (254 × 100 steps/s² = 39) |
| reg 85 = 254, TORQUE_LIMIT 600 | – | 1.00 / 75 ms | 0.56 / 173 ms | 41 rad/s² |
| **MODE 2 + host PD** (KP 2, KD 0.08, FF, ~1430 Hz loop) | 1.10 / 16 ms | 1.11 / 20 ms | 0.84 / 27 ms | – |

CSVs: `leg_sine15_r85_254_acc{0,254}_*`, `leg_sine15_r85_254_tl{1000,600}_*`.
MODE 2: `scripts/bench_mode2_pd.py` (printed table only).

- **GOAL_ACC is the working limit once reg 85 is raised; 0 means "use reg 85".**
  With reg 85 = 254, acc 50 gives 0.53 / 0.27 at 1.4 / 2 Hz (the old ceiling) while
  acc 0 or 100 gives 0.97 / 0.99 (`leg_sine15_r85_254_acc{50,100}_*`). The firmware
  wrote NOVA_GOAL_ACC 50 on every arm, which would have undone reg 85; it is now 0.
- **Reg 85 persists.** Written with the lock at 0, relocked, power-cycled: it read back
  254 and a 2 Hz sine gave 0.99 (`leg_sine15_r85_254_persisted_2hz.csv`). The status
  reply to that write came back failed even though it landed, so
  `set-servo-ids.py --set-max-accel` trusts the read-back. The #462 leg control
  servo now carries 254 permanently.
- **Position mode can pass a 2 Hz gait swing once reg 85 is raised.** The ceiling was
  a factory setting, not physics. Setting it to 254 is the LeRobot default for every
  SO-100/101 servo.
- **TORQUE_LIMIT is a PWM duty cap (#428 check 1):** at 600 the peak duty clamps at
  exactly 600 and the 3 Hz top speed drops from 2500 to 2100 steps/s. With reg 85 at 254,
  unloaded 2 Hz already peaks at 64 % duty and 3 Hz at 81 %, so a 600 cap will bite
  under load.
- **MODE 2 + a host PD loop** tracks to 3 Hz with 8-27 ms lag against 60-75 ms for
  position mode at reg 85 = 254. Ratios above 1 are overshoot: the gains are untuned.
  This loop ran at ~1430 Hz on one servo from the Mac; the Teensy runs 12 servos at a
  200 Hz tick, so on the robot the lag will be larger. Unmeasured.

## Homing convention (measured, servo ID 1)
- **home_tick = 2048** by construction: Feetech one-key center (`--center`, reg
  0x28 <- 128) sets present-position = 2048 at the held pose. Home EVERY joint
  this way at assembly (joint at nominal) -> home_tick is always 2048.
- **+tick = CLOCKWISE** viewed from the horn/output-shaft side (measured: cmd
  2048->2388 rotated the arm CW). Fixed STS3215 property.
- Per-joint `direction` sign = this CW convention combined with the servo's
  mount orientation in each leg (mirrored L/R legs flip it) — finalize during
  on-robot homing. JointMap default: home_tick=2048, direction from mount.
- 4096 cnt/rev, RAW_PER_RAD = 4096/(2*pi) = 651.9.

## Datasheet (Waveshare ST3215) — hip servo modelable WITHOUT a bench swap
~~ST3215 is ONE servo; torque/speed set by rail voltage~~ **Corrected 2026-09-25:
two different products** (Feetech datasheets): the legs' STS3215 "7.4V 19KG" (6/7.4 V,
16.5/19.5 kg·cm, 42/52 RPM, 2.0/2.5 A stall) and the hips' **ST-3215-C018 "12V 30KG"**
(12 V, 30 kg·cm, 45 RPM, 2.7 A). Different motors, same outline and 25T spline.
The table below is the two parts side by side (waveshare.com/st3215-servo.htm):
| spec | 7.4V leg rail | 12V hip rail |
|---|---|---|
| stall torque | 19.5 kg·cm = 1.91 N·m | 30 kg·cm = 2.94 N·m |
| no-load speed | ~28 RPM ≈ 2.8 rad/s | 45 RPM (0.222 s/60°) = 4.71 rad/s |
| stall / no-load current | — | 2.7 A / 180 mA |
| weight | 69 g | 69 g · op 6–12.6 V |

### Hip identification (#462, measured 2026-09-25)
`scripts/set-servo-ids.py --identify` on the Waveshare adapter at 7.5 V / 0.5 A,
one servo at a time (all at factory ID 1). Reg 0x0E = EEPROM max input voltage.

| servo | reg 0x0E | family | fw | servo ver | max torque |
|---|---:|---|----|---|---:|
| H1 | 14.0 V | **12 V** | 3.10 | 9.3 | 1000 |
| H2 | 14.0 V | **12 V** | 3.10 | 9.3 | 1000 |
| H3 | 14.0 V | **12 V** | 3.10 | 9.3 | 1000 |
| H4 | 14.0 V | **12 V** | 3.10 | 9.3 | 1000 |
| leg (control) | 8.0 V | 7.4 V | 3.10 | 9.3 | 1000 |

All four hips are the 12 V part; the leg control reads 8.0 V as the 7.4 V memory
table says, so the check separates the two on this hardware. **Firmware and servo
version are identical across both parts: reg 0x0E is the only register that tells
them apart.** Marked H1-H4 on the cases; IDs not yet assigned.

**Cross-validation:** bench peak 1800 raw @7.5V; Feetech speed unit = steps/s →
1800/4096·2π = 2.76 rad/s ≈ datasheet 7.4V no-load (~2.8). Datasheet + bench agree,
and confirms raw-speed = steps/s. ~~Hip = same servo at 12V + shared control loop
(PID 32/32/0, ~75 ms deadtime) already measured → no 12V bench swap needed.~~
Corrected 2026-09-25: the hip is a different motor, so its dynamics are NOT
measured. And the 1800 raw peak is the 60° step's accel-limited peak, not a
speed cap (the 90° step reaches 2200).

### Sim refinements this surfaced (computer-only TODO)
1. `build_mjcf` has NO joint velocity limit (`VEL=6.0` is dead code). Real caps:
   2.8 rad/s legs / 4.7 rad/s hips. Add a speed-governor/vel-limit so the policy
   can't learn unachievable joint speeds (sim2real). EFF_LEG=1.8 / EFF_HIP=2.9 ≈
   datasheet stall (1.91 / 2.94) — good.
2. `compute_inertials.SERVO_MASS` 60 → 69 g (datasheet) until a real servo is weighed.

## Online-sourced characterization (no bench needed) + corrections
Servo confirmed **60 g MEASURED** (datasheet 69 g includes horn/cable) → compute_inertials
SERVO_MASS=60 g is CORRECT, no change. Independent STS3215 teardown (robonine.com):
| property | measured | sim use |
|---|---|---|
| backlash | 0.87° (0.015 rad) | joint slop → position DR / obs noise |
| firmware deadband | **10 counts = 0.88°** | won't move below 0.88° error → small-signal tracking floor |
| repeatability | ±0.17° (~2 cnt) | matches bench settle |
| real stall torque | ~35 kg·cm@12V (>30 rated) | margin |
| speed | 45.6 RPM@100%, 21.9@50% (linear) | confirms 2.8 rad/s @7.5V |
| thermal | 70°C protect; **±90° sustained overheats ~110 min; 2 kg trips overload** | DUTY limit — gait avoid sustained high torque |
| gear ratio | 1:345 (C001, = SO-ARM101) | reflected inertia = motor × 345² |

Bus rate: 8-axis daisy-chains run fine; LeRobot/SO-ARM drive 6+ at high rate via
SYNC read/write → 12 @ 50 Hz is established (protocol supports it). No bench test needed.

⚠ **CORRECTION to any first-order phase-lag reading:** the step response is
~~RATE-LIMITED (constant-velocity traverse at ~2.8 rad/s)~~ **ACCELERATION-LIMITED
(~7-9 rad/s², corrected 2026-09-25)**, NOT first-order. Fitting
tau to settle time (324–541 ms) OVERSTATES lag — the real model is
**rate-limiter (2.8/4.7 rad/s) + ~75 ms pure delay + 10-count deadband**, not a slow
lag. Do NOT bake "-140° @1.5 Hz" into the sim; use the rate+delay+deadband model.

Ref: zeroth-robotics/bam-feetech (BAM friction sysID method — pendulum→MuJoCo, reusable
later; no STS3215 params published yet). Feetech gear variants: C001=1:345 (19.5kg,
slower, SO-ARM), C044=1:191 (faster) — confirm which SKU NOVA has.

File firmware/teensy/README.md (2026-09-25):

# Teensy 4.1 Firmware

## v1 role: BUS MASTER (Pattern B default) + safety monitor

Critical-path Phase 1 deliverable. The Teensy owns the Feetech servo bus in v1 — Jetson sends joint targets over micro-ROS, Teensy translates to bus reads/writes in a bare-metal real-time loop.

### Responsibilities

- **Bus master:** Hardware UART → 74HC125 half-duplex driver → 12-servo Feetech TTL bus at 1 Mbps (drop to 500k / 250k if bus errors emerge during bring-up)
- **Direction control:** GPIO drives 74HC125 OE pins for TX/RX gating on the shared half-duplex line
- **Real-time loop:** 200-500 Hz tick. Read joint states (position, load, temp, voltage), publish `/joint_states`. Apply latest `/joint_commands`. Hard deadline per tick.
- **Safety monitor:**
  - INA226 ×3 I²C reads (leg / hip / Jetson rails; optional 4th on L2 rail) → `/diagnostics`
  - E-stop GPIO sense — when pressed, halts servo commands and publishes E-stop event
  - **Battery low GPIO sense** — 13.03V comparator output (measured-parts value; see `hardware/wiring/README.md`'s safety-chain trip-point table) → debounce → publish `/battery_low` (Jetson subscribes, runs `systemctl poweroff` for clean SD unmount before the 12.56V hard cutoff fires — 0.47V margin)
- **micro-ROS client over USB** to Jetson

> ⚠️ **`BATTERY_LOW_PIN` fails UNSAFE on an open J20 (#435, noted 2026-09-25).** `main.cpp` sets
> pin 4 to `INPUT_PULLDOWN`, and the comparator output is active-high (HIGH = battery low). The
> `R8` 10k pull-up that makes it high is on the *power* board, across the J20 ribbon. So an
> unplugged or broken ribbon reads LOW = **"battery OK"**, silently. The E-stop input is the
> opposite (`INPUT_PULLUP`, open reads pressed), so it fails safe. For `BATT_LOW` the
> **hardware hard-cut (`HARDCUT` → Q2/Q4) is the only backstop.** It is on the power board and
> does not depend on J20. v7: invert the comparator output polarity so an open line reads
> "battery low", and flip this read to match (`hardware/pcb-mods/BUILD_PLAN.md` §8).

### Pattern A fallback path

When `JP_BUS_MASTER` solder bridge is flipped to A, the bus is driven by FE-URT-1 (Jetson direct). Teensy stays alive for INA226 + E-stop duties but stops driving the 74HC125. Used for:
- Initial servo ID assignment from workstation (Feetech FD / SCServo SDK Python)
- Debug if Teensy firmware misbehaves
- Post-mortem bus traffic inspection

### Phase 1 acceptance gate (revised — see BOM §12 step 3)

Pattern B guarantees bus-servicing isolation on the Teensy side, not full RTT through Linux. Three criteria:

1. **Mandatory:** Teensy local loop tick jitter **p99 <100 µs** over 60 seconds. This is what bare-metal bus servicing actually buys.
2. **Mandatory:** `/joint_commands` arrival rate **≥99% of 100 Hz target** over 60 seconds. Jetson + uROS healthy, command dropouts <1%.
3. *(Sanity)* End-to-end RTT median **<5 ms**, p99 **<20 ms** — Linux-bounded by USB-CDC + uROS; informational, not pass/fail.

If (1) misses → debug Teensy firmware (DMA vs ISR, UART config, ISR priority). If (2) misses → debug Jetson uROS / USB cable / CPU contention. Pattern A is not a workaround.

## Stack

- **PlatformIO** project (favored over Arduino IDE for dependency management)
- **TeensyDuino** core
- **micro-ROS for Teensy** client library
- **SCServo SDK port** for TeensyDuino (port of the Feetech Python SDK / C++ reference) — or hand-rolled minimal driver targeting STS3215 protocol
- Real-time priority on UART ISRs + DMA-driven TX/RX where possible

## ROS 2 topic contract

> ⚠️ This table is the original plan; the implementation diverged (better). Actual contract:
> `/joint_states` carries raw units (position 0..4095, effort = raw load 0..1000, servo id=i+1);
> telemetry is discrete topics (`/power_rails`, `/servo_voltage`, `/servo_temperature`,
> `/servo_present_mask`, per-class `/servo_err_*`, loop histogram stats) instead of one
> DiagnosticArray; plus `/safety_state` Int32 (latched FSM) alongside the raw `/estop` /
> `/battery_low` edge publishes, and `/safety_clear` sub. `nova_calibration`'s README documents
> the raw-unit convention — treat the code + that README as the contract until this table is
> rewritten.

| Direction | Topic | Type | Rate |
|---|---|---|---|
| Pub | `/joint_states` | `sensor_msgs/JointState` | 100 Hz |
| Pub | `/diagnostics` | `diagnostic_msgs/DiagnosticArray` | 10 Hz (INA226 readings) |
| Pub | `/estop` | `std_msgs/Bool` | event-driven |
| Pub | `/battery_low` | `std_msgs/Bool` | event-driven (13.0V trigger) |
| Sub | `/joint_commands` | `sensor_msgs/JointState` (position field) | 100 Hz target |

## ✅ Resolved 2026-06-12 (gaps from software review — both shipped same day)

1. **Command-staleness failsafe — IMPLEMENTED.** After `NOVA_CMD_STALE_TIMEOUT_US`
   (default 500 ms) without a fresh `/joint_commands`, the latched targets are overwritten
   with the latest MEASURED positions (freeze-in-place; the slew limiter makes it a gentle
   decel) and `/command_stale` (Bool, edge-published) goes true. Recovery is automatic on
   the next fresh command. Deviation from the original spec: freeze-at-measured instead of
   "slew to neutral stand" — calibration offsets live on the Jetson, so raw stand-pose
   values are meaningless at this layer.
2. **Boot-broadcast gate — bonus bug found during implementation.** `broadcast_servo_commands()`
   used to SYNC_WRITE the all-zeros latched array at 40 Hz from power-on — on real hardware
   that slams all 12 joints to raw position 0 before the first command. Now gated on
   `joint_cmd_rx_count > 0`: the bus is never written until the host has commanded at
   least once.
3. **`/battery_low` → poweroff — IMPLEMENTED in nova_ops** (`battery_shutdown_node`,
   §10 in `ros2_ws/src/nova_ops/README.md`; sudoers prereq in `docs/setup-jetson.md` §15).

Adversarial review, same day — three more, all fixed:

4. **74HC125 OE polarity inverted** (`feetech_bus.h set_tx/set_rx`). The '125's
   output-enables are ACTIVE-LOW; firmware drove both HIGH for TX / both LOW for RX.
   Net effect on real hardware: TX buffer tri-stated during transmit (bus never driven)
   AND the idle-high UART driving the bus through the TX gate during receive (contention
   with every servo response). Verified against the logic-board netlist (U7 gate1
   OE̅=OE_TX, gate2 OE̅=OE_RX, no inverters) and corrected. **Bench-verify with a scope
   on first contact anyway** — this is the highest-consequence polarity on the board.
5. **SYNC_WRITE stack buffer overflow.** 12-servo goal broadcast = 44-byte frame into a
   `MAX_FRAME_LEN`(=38)-byte stack array — 6 bytes of stack smashed at 40 Hz. Invisible
   with ≤10 servos on a bench, memory corruption with the full fleet. `MAX_PARAM_BYTES`
   32→40 plus an explicit frame-size guard in `sync_write_goal_positions()`.
6.5 **(pass 2) Cold-boot brick.** micro-ROS init ran in `setup()` BEFORE the tick timer,
   and `RCCHECK` bricked into a while(1) on failure — but the agent lives on the Jetson,
   which boots 30-60 s after the Teensy. Every real robot power-up bricked the firmware
   (no watchdog running yet) until a manual power cycle; dev flashing masked it because
   the agent was already up. `rclc_support_init` now retries forever with a 2 Hz LED blink.
   Motion is impossible pre-agent anyway (broadcast gates on first command) and the
   hardware safety chain is autonomous.
6.6 **(pass 2, nova_calibration) Hard-stop probe goal runaway.** The probe advanced its
   goal open-loop; against a compliant stop (printed PA6 flexes) load could sit below
   threshold while the goal ran to the 0/4095 clamp, grinding gears at rising torque.
   Goal now leashed to `leash_raw`(=24) past the last measured position — worst-case
   torque bounded, compliant stops resolve as TIMEOUT instead of silent grinding.
   Regression-tested (`test_hard_stop.py`, 7/7).
6. **Edge-only safety topics blinded late joiners.** `/estop`, `/battery_low`,
   `/safety_state`, `/command_stale` published only on change — a respawned
   battery_shutdown node (or preflight on a quiet bus) could never learn an
   already-latched state. All four now also re-publish at 1 Hz from the heartbeat.

## Open questions for firmware phase

- DMA vs ISR for UART TX/RX (DMA preferred for jitter; ISR simpler)
- Per-servo poll interval — round-robin all 12 vs prioritize legs over arm/idle joints
  (current: 1 servo/tick = 16.7 Hz per joint; budget fits 2/tick if closed-loop work
  ever needs faster feedback)
- Failure-mode behavior: lost servo response → retry budget → flag dead in `/joint_states`
- micro-ROS QoS profile — recommended resolution: `/joint_commands` best-effort keep-last-1
  (stale commands are worse than none), safety/state topics reliable

Resolve during firmware bring-up.

---

> **Status (2026-05-23):** Firmware end-to-end on Jetson, 20-topic contract live, **loop p99 = 1 µs** (50× under <100 µs acceptance gate) after IntervalTimer ISR-driven 200 Hz tick replaced polled loop. Recent additions (2026-05-19 → 2026-05-21): safety FSM (E-stop + battery-low latch + `/safety_clear`), full STS3215 telemetry (pos+vel+load + voltage + temp @ 5 Hz), per-joint slew limiter on SYNC_WRITE broadcast, software watchdog (ISR-checked main-loop progress + AIRCR reset on hang), boot-time servo ping sweep populating real `/servo_present_mask`, INA226 → `/power_rails` Float32MultiArray @ 10 Hz, `/firmware_version` + boot self-test for safety GPIOs, categorised bus errors (timeout / bad_frame / servo). CI green on every PR.
>
> **Untested on wire** (skeletons compile-green, behavior unverified): `feetech::Bus` SYNC_WRITE broadcast against real STS3215, INA226 I²C reads against real breakouts, 74HC125 half-duplex driver gating. Phase 1 bench bring-up gate: re-measure `/loop_exec_p99_us` once real bus + I²C are in the hot path (skeleton 1 µs will grow). Live TODO in `firmware/teensy/firmware/README.md`.

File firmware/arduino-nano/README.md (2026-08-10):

# Arduino Nano Firmware

**Reduced role per BOM v3.5 cut (2026-05-24).** No more I²C aux bus.

## What the Nano drives

- **SSD1331 96×64 OLED** via SPI — battery / IP / gait state display
- **WS2812B RGB LED strip × 4** via 1 GPIO — at-a-glance robot status
  (per `docs/notes-qol-features.md` §8)

## What's gone (cut from v1, on shelf)

- ~~PIR motion sensors × 3~~ (wrong sensor class for mobile robot)
- ~~HC-SR04 ultrasonics × 2~~ (D456 + L2 perception redundant)
- ~~MPU-6050 IMU~~ (D456 + L2 IMUs higher-quality)
- ~~DFPlayer Mini Pro + speaker~~ (novelty; Phase 4 polish)

## Architecture

```
Jetson ──USB-serial──► Arduino Nano ──SPI──► SSD1331 OLED
                                 │
                                 └─GPIO──► WS2812B LED strip
```

Jetson side: `nova_ops/oled_status` node (stub committed) subscribes to:

- `/battery_low` (Bool) — safety latch state
- `/safety_state` (Int32) — 0/1/2/3 → LED color
- `/firmware_version` (String) — boot splash
- `/joint_cmd_rx_count` (Int32) — gait liveness
- `/power_rails` (Float32MultiArray) — battery voltage

Packs into 4-line text frame + 1 LED state byte. Writes over
`/dev/ttyUSB0` @ 115200 baud.

## Protocol (proposal)

Line-based ASCII, one command per `\n`:

```
STATE <0..3>            # sets LED color (0=OK green, 1=ESTOP red,
                        #                 2=BATT_LOW amber, 3=FAULT red blink)
LINE <0..3> "<text>"    # sets one of 4 OLED text rows, 16-char max
SPLASH                  # show firmware_version briefly
```

Nano echoes acknowledgments (`OK\n` / `ERR\n`) so the Jetson side
can detect a dead Nano.

## Wiring (final layout TBD with PCB v6)

| Nano pin | To | Notes |
|---|----|----|
| D11 (MOSI) | SSD1331 SDA | SPI |
| D13 (SCK) | SSD1331 SCK | SPI |
| D10 | SSD1331 CS | SPI chip select |
| D9 | SSD1331 DC | data / command |
| D8 | SSD1331 RST | reset |
| D6 | WS2812B DIN | 800 kHz NeoPixel data |
| 5V | OLED + LED Vcc | regulated 5V |
| GND | common | |
| USB | Jetson USB port | serial bridge |

## Sketch (TODO)

- **The OLED has a mount: `oled_tray.scad`** (#35, 2026-08-10) — flat on the rear
  shoulder deck, looking up. It REPLACED `oled_mount.scad`, which is deleted.
  Superseded note follows: `oled_mount.scad`
  exists and bolts to the `control_pod` deck, but its 4 board mount holes were
  removed 2026-07-28 (**#35, open**) — the vendor drawing never gave the hole
  pitch, and the guessed pitch put 2 of 4 holes inside the display window. Three
  caliper numbers off the owned module unblock it (both pitches + the active
  area and its datum offset); see `docs/checklists/caliper-session.md` §6. The
  electrical side is ready either way: `J10` and the `R2`–`R6` 1k series
  resistors are on the fabbed logic board.
- Status: not implemented yet — **this directory contains no source at all**,
  only this file. "The OLED + LED hardware works standalone" means the modules
  themselves are known good, NOT that anything drives them: the `oled_status`
  ROS node is a stub and there is no sketch for it to talk to.
- Libraries: Adafruit_GFX + Adafruit_SSD1331 + FastLED.
- Roughly 1-2 evenings of work. Phase 1 polish task.

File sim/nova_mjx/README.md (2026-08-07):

# NOVA MJX — virtual walking training

Train a NOVA walking policy in simulation (MJX, GPU-parallel MuJoCo) with Brax
PPO, then deploy the learned policy to the Jetson. Built for **no local GPU** —
develop + validate on your Mac (CPU), train on a **free Colab GPU**.

## Files

| file | what |
|---|---|
| `build_mjcf.py` | generates `nova.xml` (MJCF) from the measured link lengths + CAD inertials — same source of truth as `nova_description` |
| `nova.xml` | the MuJoCo model: floating trunk + 4 legs, STS3215 position servos, foot/trunk collision, IMU + joint sensors, stand keyframe |
| `validate_model.py` | CPU check — compiles, right DOF, **stands** under gravity |
| `env.py` | MJX joystick locomotion env (Brax `PipelineEnv`): obs / action / reward / **domain randomization** |
| `train.py` | Brax PPO trainer → pickled policy |
| `requirements.txt` | deps |

## 1. Local (Mac CPU) — validate before burning Colab time

```bash
# python 3.11/3.12; pinned combo (see requirements.txt for why the versions)
pip install "jax[cpu]==0.6.0" brax==0.14.2 "orbax-checkpoint>=0.11.22" mujoco mujoco-mjx
python build_mjcf.py          # -> nova.xml
python validate_model.py      # -> "STANDS ✓"
JAX_PLATFORMS=cpu python -c "import jax,jax.numpy as jp; from env import NovaJoystick; \
  e=NovaJoystick(); s=jax.jit(e.reset)(jax.random.PRNGKey(0)); \
  print('obs',s.obs.shape); print('step ok', jax.jit(e.step)(s, jp.zeros(12)).reward)"
```

The env builds + steps on CPU (obs dim 105 (3-frame history), 12 actions) — good enough to confirm
correctness. **Do not train on CPU** (too slow).

## 2. Train on Colab (free T4 GPU) — checkpointed, survives disconnects

New Colab notebook, **Runtime → change type → T4 GPU**. **Mount Drive first** so
checkpoints survive a disconnect (Colab's `/content` is wiped when the runtime
dies — a local checkpoint dies with it):

```python
from google.colab import drive; drive.mount('/content/drive')
# PINNED versions — brax 0.14.2 only works on jax 0.6.x (see requirements.txt)
!pip install -q "jax[cuda12]==0.6.0" brax==0.14.2 "orbax-checkpoint>=0.11.22" mujoco mujoco-mjx
# upload build_mjcf.py, env.py, train.py  (Files panel, or clone the repo)
!python build_mjcf.py
!python train.py --ckpt /content/drive/MyDrive/nova_ckpt --timesteps 40_000_000
```

Brax writes a full checkpoint (params + normalizer) **every eval** to `--ckpt`.
`eval_reward` climbs over ~20–40 min on a T4.

### If Colab disconnects / crashes partway through
**Just re-run the same `train.py` cell.** It finds the latest checkpoint under
`--ckpt` (by mtime, robust across many resumes) and **continues from it** — no
progress lost. Re-run as many times as needed; each invocation trains
`--timesteps` more from wherever the last checkpoint left off. The run log
(`--ckpt/train_log.csv`) and the latest `nova_policy.pkl` also survive on Drive.

*(Verified end-to-end on CPU: save → find-latest → restore → continue.)*

Scale `--timesteps` up for a cleaner gait; tune the reward weights in `env.py`.

## 3. Robustness — so the trained policy holds up to real failures

The env is built to survive the sim-to-real gap and physical mishaps, not just
walk on flat ideal ground:

- **Observation HISTORY** (3 stacked proprioceptive frames) — the biggest
  transfer lever after actuator fidelity: gives the policy the memory to infer
  velocity / contact / latency from real-only sensors, and removes the need for
  foot-contact sensors NOVA doesn't have (contact is inferred from the joint-vel
  history). Obs = IMU + servo feedback + command only (105-d).
- **Observation noise + a per-episode IMU gyro bias** (real ICM-42688-P drift).
- **Jerk + stand-still penalties** — smooth motion, no idle shuffling (less servo
  wear, better transfer).
- **Randomized start** — random base velocity + joint pose each episode, so the
  policy learns to recover from off-nominal states, not just the home stance.
- **Mid-episode pushes** — a random base-velocity kick every ~150 steps; trains
  active recovery from a shove / stumble / slip (a *physical* failure partway
  through a walk).
- **Feet-air-time reward** — rewards a real stepping gait with ground clearance,
  not a foot-dragging shuffle that face-plants on any bump.
- **Domain randomization** (`domain_randomize`): floor friction, **per-link**
  mass (±15%, every body), actuator gains, and per-env **TERRAIN**.
- **Terrain curriculum** (`terrain.py`) — each env gets its own heightfield at a
  random difficulty (`level` 0→`TERRAIN_MAX`): a **flat center pad** (spawn zone)
  with rough bumps + slopes roughening outward. The blind-locomotion foundation
  (rough ground, slopes). **Train FLAT first** (`TERRAIN_MAX = 0.0` in
  `terrain.py`) to get basic walking, then raise to `1.0` for terrain robustness.

### Stairs
This terrain is the BLIND foundation (uneven ground / slopes / gentle steps) —
enough to harden flat walking and handle rough floors. **Foot-precise stairs
need exteroception**: a LiDAR **height-map** obs (elevation grid from the L2 —
the lidar self-filter feeds it) + a bigger net. That's Phase 3, not this.

## 4. Watch the trained gait

```bash
pip install imageio imageio-ffmpeg
python rollout.py --policy nova_policy.pkl --vx 0.5 --steps 400 --out walk.mp4
```

Steps the policy with a fixed forward command, records qpos, renders it in
MuJoCo with a follow-cam → `walk.mp4` (prints how far it traveled in x). With no
`--policy` it renders a zero-action stand — a quick way to test the render path
before training. **Headless (Colab/servers): `MUJOCO_GL=egl python rollout.py …`**
(on macOS use the default, don't set it).

## 5. Deploy to the Jetson

```bash
# export the trained policy (on the training machine / Colab)
python export_policy.py --policy nova_policy.pkl   # -> nova_policy.npz (+ .onnx)
```

- **`export_policy.py`** — extracts the deterministic policy (normalizer + 4×128
  MLP) into `nova_policy.npz` (**numpy weights — the Jetson runs it with zero
  heavy deps**) and `nova_policy.onnx` (portable, optional). Verified numerically
  against the Brax policy (~1e-8).
- The ROS 2 bridge is `ros2_ws/src/nova_locomotion/nova_locomotion/policy_node.py`
  (#289) — a real colcon package now, not a scaffold. `joint_states` + `imu` +
  `cmd_vel` @ 50 Hz → policy → `/joint_commands`, through the SAME
  `SafeJointCommandPublisher` + homing-calibration path `gait_node` uses,
  gated on preflight + full (12/12) calibration + a live `/imu` + explicit
  arming (`/nova/policy_enable`, default off):
  `ros2 launch nova_locomotion policy.launch.py policy_npz:=nova_policy.npz`.
  `deploy/policy_runner.py` moved with it, to
  `nova_locomotion/policy_runner.py` — same pure numpy module, one copy.
  `deploy/policy_node.py` is now a deprecation stub (raises on import) so the
  old `/joint_goal_ticks` topic (zero subscribers) can't come back by accident.
- **`policy_runner.py`** (now under `nova_locomotion/`) — framework-free
  runner (numpy only). `build_obs` reproduces sim's 105-d history obs
  EXACTLY; `joint_targets(sensors) -> 12 rad targets`.
- **`deploy/test_policy_runner.py`** / **`deploy/test_policy_contract.py`** —
  still live here (path-inserted at the new `policy_runner.py` location) and
  still pass; `test_policy_runner.py` cross-checks `build_obs` against the sim
  env byte-for-byte (obs mismatch = silent transfer failure), `test_policy_contract.py`
  checks the same numpy-only, no jax/brax needed. `nova_locomotion/test/test_policy_runner.py`
  carries the numpy-only contract checks into the ros-pytest CI job.

⚠ Still bench-blocked: no IMU driver yet (#14) — `policy_node.py` refuses to
enable without a live `/imu` stream, by design, until the ICM-42688-P lands.
And no checkpoint has been pulled onto the robot yet (#288) — the node refuses
to start at all without a `policy_npz` that exists on disk.

## Provisional / to refine

- **Inertials** are CAD estimates (mesh volume × effective PA6-CF density +
  servo box); the hip tensor is diagonal (its CAD frame is mirror-handed — see
  `build_mjcf.py`). **Weigh the printed links** and rescale (backlog #5).
- **Servo model** — position actuator, now domain-randomized over kp/kv/joint-
  damping **plus control latency** (per-env action delay). Once you measure a
  real STS3215 step response, NARROW the DR ranges around the measured values
  (`env.domain_randomize`) — the biggest remaining transfer-gap closer.
- **Migration:** Brax `PipelineEnv` is in maintenance mode; the actively-
  developed path is **[MuJoCo Playground](https://github.com/google-deepmind/mujoco_playground)**
  (MJX-native locomotion envs + DR). `nova.xml` drops straight into it when you
  want to move over — the model is the reusable asset, the env is the wrapper.

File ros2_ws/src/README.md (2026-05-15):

# ROS 2 Workspace — `src/`

Colcon workspace for ROS 2 Humble packages.

## Planned packages
- `nova_description` — URDF/xacro for quadruped + arm
- `nova_bringup` — launch files for full stack
- `nova_servo_bus` — micro-ROS bridge node (Jetson side). Topics paired with the Teensy firmware (see [`firmware/teensy/`](../../firmware/teensy/)). v1 uses Pattern B (Teensy is bus master); no direct FE-URT-1 driver path in this package.
- `nova_gait` — 8-phase walk gait controller
- `nova_ik` — 3-DOF-per-leg inverse kinematics solver
- `nova_perception` — RealSense + L2 fusion launch
- `nova_slam` — POINT-LIO and/or RTAB-Map configs
- `nova_nav` — Nav2 params for legged platform
- `nova_vla` — VLA policy node (Phase 4)

External clones (vendored or `vcs import`):
- `realsense-ros` (Intel)
- `unitree_lidar_ros2` (discodyer fork)
- `micro_ros_setup`

Build: `colcon build --symlink-install`

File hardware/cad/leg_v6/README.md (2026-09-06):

# Leg V6 — functional STS3215 leg (designed-for-assembly)

> Top-level design: [`docs/design-outline.md`](../../../docs/design-outline.md)

Started 2026-07-02. Supersedes the leg_v5 carve-a-cavity approach, which had no
servo insertion path, no retention, and no serviceable joints (user call —
correct: those were blocks, not leg designs).

## Design pattern (every joint, every part)

- **Servo mounting:** drops into an **open-top pocket**, 4× **countersunk M2
  self-tap** through the pocket floor into the case's bottom pilot holes. Lifts
  straight out for service. 🔴 *Read "M2.5" and cited the "9.9×9.9 square" until
  2026-08-02 — both wrong: the case screws are **M2**, and the 9.9×9.9 square is
  the DISC bolt pattern, not the case pattern.* **STEP-verified 2026-08-02:** the
  case pilots are **8× Ø1.5** (with Ø4.2 head recesses) at **y=±10.25** on the two
  shaft-normal faces, x = +4.20 / −20.30 on the bottom face. Subtract the 12.5 mm
  spline offset → **(−8.3, ±10.2) and (−32.8, ±10.25) = `COL_PTS` exactly.** The
  pocket geometry is right. ⚠️ The STEP models these pilots only **1.5 mm deep**;
  the real column is **7.0 mm measured** — and never the 19.9 mm that older docs
  back-solved from a 22 mm screw. Note the faces are **asymmetric** (top face is
  x = +4.20 / −16.50); leg_v6 mounts through the **bottom** face.
- **Driven joint = yoke:** top arm bolts to the Ø20 output horn (4× **M3** on
  Ø14 BCD ±45° + M3 center); bottom arm pivots on an **M3 shoulder screw into a
  heat-set boss (M3 × D4.6) in the pocket floor**, coaxial with the spline.
  🔴 *Disc fastener was "M2.5" until 2026-08-02 (#263) — it is Ø3.0 nominal, though
  tapped-M3 vs PA3.0 self-tap pilot is UNRESOLVED (#262). The
  ∅2.5 holes in the STEP are the M3 tap drill, not M2.5 clearance (2.9).*
  The Ø20 bolt-on bottom wheel is NOT used — it and the case-screw square both
  occupy r<10 of the bottom face (mutually exclusive with floor mounting), and
  the boss routes joint side-load into the printed bracket, not the servo case.
- **Wires:** slot out the knee-side pocket wall into an open-top channel.
- **Kinematics LOCKED to B2 measured numbers** (`dimensions.md §6`):
  femur 106.9 · tibia 129.0 · lateral jog 30.5 — URDF/IK stay valid.

## Parts

| Part | Status | Notes |
|---|---|---|
| `leg_v6_common.scad` | ✅ rev 2 | mesh-verified servo frame, pocket/platform/horn-couple/wheel-boss/strap/zip modules; CLR_POCKET 0.45 DROP-IN |
| `femur.scad` (+`_L`) | ✅ gated | HFE pocket, knee fork w/ FLAT SHELF (top arm is bolt-on), wheel boss, vents, cable groove+anchors, strap pads, side dots; **zero bridging** |
| `knee_arm.scad` (print 4) | ✅ gated | bolt-on knee top arm — horn-seat face prints ON BED; 4× M3 into shelf heat-sets, diagonal pair Ø3.1 close-fit (registration) |
| `tibia.scad` (+`_L`) | ✅ gated | KFE pocket + blade + **toe_v2 designed seat** (disc/boss/key-pockets, mates the SM3_Foot crescent — `check_shoe.py` gated) @129.0, jog −30.5 outboard (stock stance); vents, anchors, dots |
| `coax.scad` (+`_L`) | ✅ gated | HAA pocket (horn −Y, front insert), femur yoke (horn arm 16.6 / wheel boss →51.5, bridge 7.4), front strap pads, vent, bottom cable tunnel |
| `strap.scad` (print 4+) | ✅ | servo tail retention, 2× Ø3.2 zip-tie bores into rim-pad zip cuts (2026-07-16: was M2.5 self-tap — see row 15) |
| `shoulder_plate.scad` (+`_L`, 4 installed = 2 per side) | ✅ gated | L-bracket hanging off the shoulder deck — vertical face bolts the haa HORN, top flange bolts down into the deck heat-sets; drop 4 screws + 1 plug and the whole leg comes off. **⚠ HANDEDNESS IS NOMINAL (measured 2026-08-02): `_L` is the SAME SHAPE.** The body is symmetric about its own midplane (x=39), so `mirror([1,0,0])` is a pure translation; the only asymmetric feature is the LA-2 dot (volume delta 7.41 mm³ = one Ø3×1.1 dot). Consequences: **both print horn-seat-down in the same orientation** (LA-3's L-orientation warning is for the Z-mirrored femur/tibia, not this), and **a plate on the wrong side is a non-event** — dots here are bookkeeping, not hazard prevention. ⬜ material still INFERRED not sourced (#184) |
| shoulder (+`shoulder_sw1` front, #377) | ✅ gated (rev 2026-07-06; `shoulder_sw1` gated #393) | v6 crossmember per trunk end; **riser interface rev**: flange center notch (x ±26 above z 19.5) + 2× Ø3.4 riser hold-down holes (x ±40, z 26.95) — see `../chassis/README.md`. `mesh_health.py` runs against both `shoulder.stl` (rear, plain) and `shoulder_sw1.stl` (front, + SW1 panel hole); the haa roll sweep (`check_fit.py --sweep`) runs against `shoulder.stl` only — the SW1 cutout sits 27-40mm from the swept hip, so `sw1_cutout_check()` proves the cutout instead (exists, in its designed box, ≥25mm from both hip roll axes) |

**ROM (sweep-gate verified, LEG-LOCAL):** kfe ±109° sw / ~118° mech ·
hfe ±86° sw · haa ±40° = shoulder input. **CHASSIS-SAFE caps are tighter**
(`../chassis/check_fit.py` is the authority for the assembled robot):
hfe toward-trunk +50 sw · haa INBOARD +15 sw (outboard keeps 40) — these
feed the URDF/firmware, not the leg-local numbers. `./build_all.sh` runs
the full gate (6 pockets + pose sweeps) on every build. Side dots:
**1 = RIGHT, 2 = LEFT**.

**v6 lateral chain** (URDF updated, sum still 64.3 = IK d): haa→femur-mid **33.8** ·
femur/tibia coplanar **0** · foot post **30.5**. Stock split was 24.6/9.2/30.5.

Full-leg fit view: `preview_leg_assembly.scad` (coax + femur + tibia + ghost servos).
`./build_all.sh` renders all 6 STLs (R+L).

## rev 2 — pocket + joints rebuilt against the full servo model
The original "case bottom thread square" was a misread (those holes belong to
the horn/wheel discs). rev 2, from `feetech_servo_models/converted_stl/servo.stl`:
- **Mounting:** the servo's own 4 case-screw columns — replace the stock
  self-tappers with **longer M2 screws through the pocket floor** (countersunk;
  measure stock length at first article, spec ≈ stock + 3mm). SO-ARM style.
- **Joints bolted BOTH sides:** yoke top arm on the Ø20 horn (4× **M3** BCD14 +
  M3 center); yoke bottom arm's **Ø19 boss reaches through the Ø21.5 floor
  window and bolts the Ø20 BOTTOM WHEEL** (standard-fitted; 4× **M3**, **NO
  center screw** — idler side, #51/LA-5; head counterbores modeled at Ø6.0).
  No heat-set/idler-boss hack. 🔴 *"M2.5 + M2.5 center" until 2026-08-02: the
  thread is M3 (#263) and the wheel center screw was retired in #51.*
- **Cables:** the case's rear-bottom connector bay (3.9 deep) is seated by the
  floor; sockets face rearward mid-body — **plug before drop-in**, wires lie in
  the bay and exit the end-wall tunnel (femur/tibia: toward the joint below;
  coax: out the bottom).
- **Strap:** retention strap over the servo tail on raised rim bosses (the
  case's rear top cap ridge stands 2.7 proud of the rim plane).

## Hardware per joint
4× **M2×9** CSK (case columns — **not** "stock+3mm"; floor 2.125 + 7.0 measured
column = 9.1 max, and the HFE-far pair takes ×13 on its ramped floor) · 4+1×
**M3×6** (horn + M3 center) · 4× **M3×8** (wheel, through boss, counterbored,
**no center screw**) · strap retention: **tibia**
zip tie (2026-07-16, Ø3.2 through-bore — see row 15); **coax** also zip tie
(2026-07-16, coordinator follow-up — Ø3.2 through-bore at x=±15.60 in its own
separate strap-pilot cut, coax.scad — hand-converted, not a
`strap_pilot_neg()` call, same axis-different-frame reason as before; 1.15mm
verified clear to the servo cavity, outboard side left thin/open to avoid
the known femur-rim graze at x≳16.6).

## Connection & tolerance map (audited 2026-07-06)
Every mate, its fit, and who provides location:

| # | Connection | Nominal fit | Locates via |
|---|---|---|---|
| 1 | servo body ↔ pocket walls | 0.45/side DROP-IN slip | — (guide only) |
| 2 | case columns ↔ floor holes | M2 in Ø2.3 (+csk Ø4.6 cone) | the 4 screws, ±0.15 → THE servo locator |
| 3 | case front-bottom ↔ platform | 0.1 axial seat gap | — |
| 4 | bay ↔ bay seat | 0.3 axial | — |
| 5 | horn Ø20 ↔ arm recess | Ø+0.3 (CLR_HORN 0.15), 0.4 deep | recess + 4×**M3** BCD |
| 6 | horn face ↔ arm underside | bolted contact | — |
| 7 | wheel Ø20 ↔ boss face | flat clamp, NO radial feature (impossible: boss 19 < wheel 20) | the 5 screws, ±0.2 |
| 8 | boss Ø19 ↔ floor window Ø21.5 | 1.25/side swing | — |
| 9 | wheel Ø20 ↔ window Ø21.5 | 0.75/side spin | — |
| 10 | tibia in femur slot (axial) | horn contact top / 0.4 bottom gap | bolted discs |
| 11 | tibia disc r16.05 ↔ slot | 1.0/side | bolted discs |
| 12 | femur disc r16.05 ↔ coax void r16.7 | 0.65 radial (was 0.35 — under print tol, widened) | — |
| 13 | knee arm ↔ shelf | flat + 2× Ø3.1 dowel-fit M3 (0.12) + 2× Ø3.4 | dowel screws |
| 14 | M3 heat-sets | **bore Ø4.0** (insert OD 4.6 — a 4.6 bore drops through; audit catch). ⚠ 2026-07-06: `HEATSET_D/L` were referenced but NEVER DEFINED — OpenSCAD silently dropped every insert bore from femur + shoulder STLs; now defined in `leg_v6_common.scad`, STLs rebuilt. If a printed femur/shoulder predates this, its shelf/deck has NO bores — reprint | — |
| 15 | strap ↔ pads | **zip tie** (2026-07-16, was M2.5 self-tap — 0.374mm wall to the servo cavity, no insert/nut fits, banned project-wide): Ø3.2 through-bore in the boss/rim (`strap_pilot_neg()`) + matching Ø3.2 bore in the strap, both at ±15.60 (shifted outboard off the old 14.25 for ≥1.0mm wall — 1.15mm boss-side / 1.44mm strap-side, TRIMESH-PROBED); pad top 17.6+, cap gap ≥0.2 | — |
| 16 | toe_v2 seat ↔ SM3_Foot | **designed seat** (2026-07-06, replaces the stock outline — it never mated the crescent, sloppy ring): core disc r12.35×14.2 on the shoe's inner face r12.53 (0.18 clr), boss r10.15 under the edge lips (r10.35), 2 sector key pockets take the mid-band tabs (tips r6.88); θ = 54 exactly, ±~2° slop. Contact plumb under the post by construction (dimensions.md SM3_Foot **v3**). **Gated: `check_shoe.py`** (0 penetration, seat gap median 0.28) | key pockets |
| 17 | cable plugs ↔ tunnel | 19×5.9 tunnel — **✅ AUD-3 RESOLVED 2026-07-10 (user caliper)**: real servo dual-connector exits side-by-side at 15.1mm (< 19 tunnel width), plug height <5.9mm (< tunnel height) — the cabled servo passes the tunnel plugged-in, no pocket change needed | — |
First-article: run an M3 through the Ø3.1 dowel pair (prints ~3.0), M2 through
columns, insert purchase test at Ø4.0 before committing the knee arms.

**Corner identity:** only TWO leg variants exist (L/R), two of each — but they
go on **DIAGONAL** corners, not one variant per side (**CORRECTED 2026-07-26**;
this section previously said "front and rear are the same parts translated").
`shoulder.scad` is the same crossmember GEOMETRY at both trunk ends and its
flange bolts to the trunk **end face**, so the rear crossmember is the front one
**yawed 180° about the vertical** — which flips which chirality each rear corner
needs. (**Since #377, 2026-08-15, the two ends are no longer the same PART**:
the front adds the SW1 Contura panel hole and prints from `shoulder_sw1.scad`,
the rear stays plain from `shoulder.scad`. One source, one flag, two STLs. The
yaw argument below is unaffected — it is about placement, not about the hole.) Verified
against the meshes (`../chassis/check_fit.py` `coax_to_trunk_bases()`, fixed the
same day; `docs/cad-review-2026-07-26.md` §1):

| corner | coax / femur / tibia | hip station | hfe axis (trunk frame) |
|---|---|---|---|
| FRONT +y | R parts | x +141.2 | x **+129.6** (11.6 toward the trunk) |
| FRONT −y | L parts | x +141.2 | x +129.6 |
| REAR +y | **L parts** | x −141.2 | x **−129.6** |
| REAR −y | **R parts** | x −141.2 | x −129.6 |

A wrong-chirality leg is caught immediately at assembly (its femur yoke points
*inboard*, under the trunk) — but plan the print batch and the pre-assembly
kitting off the table above, not off "L on the left, R on the right".

An ASSEMBLED leg becomes corner-specific via its servo
IDs (FL 1-3 · FR 4-6 · RL 7-9 · RR 10-12): after ID assignment + centering,
LABEL the coax (tape/marker: corner + IDs). The two legs of the SAME chirality
(now FL↔RR / FR↔RL) are physically identical — swapping them scrambles the gait
with zero visual cue.

## Fit gate (run after every geometry change)
`../../../.venv/bin/python check_fit.py` — places the REAL servo mesh
(`feetech_servo_models/converted_stl/servo.stl`) at each pocket pose and
samples 21k points against the part solid; any point inside = the part cuts
the servo. Wired into `build_all.sh`. Caught the bay-width error the box
model missed (real bay = full case width).

## Assembly order (constraint, not preference)
1. Bolt femur↔coax (hfe horn + wheel) — the horn screws are driven THROUGH
   the empty haa pocket; 2. plug + drop the haa servo, floor screws + strap;
   3. tibia↔femur anytime; 4. shoulder last. Servicing hfe = pull haa servo.
Keep 2-3 spare horn discs (hard falls can strip a spline).

### Cable dressing (backlog #18 — `cable_clip.scad`, TPU 95A, 20 installed = 5 per leg × 4)
Each flex zone gets a **clip at BOTH loop ends** (the existing zip tie
threads the leg's Ø3.2 pair AND the clip's matching holes — no leg mods):
- HIP loop (haa+hfe flex): coax tunnel-exit pair + femur x44 pair
- KNEE loop (kfe flex): femur x84 (yoke plate) + tibia x44 pair
Rules: loop radius **≥40 mm** (8× the Ø5 bundle) between clips — the
clip's bell-mouths control the exit bend, the spiral wrap (Ø6, BOM)
covers the free loop; zero tension at any plug (clips+ties take it);
**tug-test all 24 connector ends + every anchor** at assembly (#25).
femur x52 pair stays a bare-tie spare anchor.

**Free-loop length (backlog #18 / LA-14, `--cable` WARN gate, LA-20):**
the anchor separation itself SHRINKS across ROM below the ≥40mm-radius
(≥80mm-span) spec — KNEE loop (femur-x84 ↔ tibia-x44) drops to **~39mm**
at full kfe fold; HIP loop (coax tunnel-exit ↔ femur-x44) swings
**~60-79mm** across hfe. This is left OPEN as geometry (see LA-14) and
resolved by ASSEMBLY DISCIPLINE instead: dress each loop with slack
sized to the loop's own worst-case (tightest) span, not its neutral-pose
span. Concretely — **fold the joint to its mechanical limit FIRST, THEN
route + zip-tie the loop to both clips** so the loop is slack (never
taut) at full fold and simply has extra spare at neutral. Never dress
a loop at mid-ROM/neutral and call it done; that leaves it taut (and a
fatigue point) at the mechanical stop.

## Pre-walk firmware gates (from movement review)
Boot-settle ramp (PR #17) · servo torque limits written (open audit item —
trip backdrive protection) · stand-up keeps feet under knees (knee ≤80%
rating with splayed push-up).

## Verify (first-article print, before batching)

> **FIRST-ARTICLE RESULTS — 2026-08-10 (right leg, parts printed 08-02/08-06).**
> Recorded here because this list was written for exactly this run and read as
> untested until now.
>
> | # | check | result |
> |---|---|---|
> | 5 | **Yoke gap** 0.2-0.6 mm — *the one that can send the CAD back* | ✅ **PASS** — fits well |
> | 1 | **Servo pocket** drop-in, no rock about Z | ✅ **PASS** — seats, ribs visible |
>
> ⚠️ **"Slides in easily, extra room at the sides" is the DESIGNED feel, not a
> defect** — and it reads like one, which is why it is written down. The ribs are
> ramped at the mouth (`ANTIROT_MOUTH_PROUD` 0.02) and only reach full
> `ANTIROT_PROUD` 0.35 below z 10.5. Free drop ~1.7 mm → easy for 2.5 mm → light
> thumb press. Ribs present + seats + no rock = pass.
>
> 🔑 The rib check was the one that mattered and could not have been caught by
> feel: they are a RETENTION feature. Without them the joint torque reacts
> through 4 M2 **self-tap screws in the servo's own plastic columns** →
> back-out/wallow at ~1e5 cyc/hr (`servo_pocket_analysis.py`; no static SF
> captures it). With them the walls take it, SF 573, screws axial-only.
>
> ⬜ **Still to record:** does the RIB crush or the servo CASE score after a few
> insertions? The wall-bearing analysis assumes the rib profile survives.
> ⛔ **Items 2/3 (M3 through the horn BCD) are BLOCKED** until `knee_arm` ×1 and
> `shoulder_plate` ×2 (printed 08-02, pre-#263) are drilled Ø2.9 → 3.4.

1. Pocket fit (CLR_POCKET 0.45/side) — **this is NOT a free drop all the way
   down, and a print that needs a thumb press is not a failed print** (#167).
   The anti-rotation ribs stand `ANTIROT_PROUD 0.35` into a 0.45 pocket, so
   the nominal clearance AT THE RIBS is **0.10 mm/side** — inside the very
   print tolerance that 0.45 exists to absorb. What a good part feels like:

   - **free drop for the first ~1.7 mm** (`ANTIROT_Z[1]` = 13 sits that far
     below `CASE_TOP`, so nothing touches yet), then
   - **increasing resistance over the next 2.5 mm** as the `ANTIROT_LEADIN`
     taper engages (full-crush zone starts at z 10.5), then
   - **seats with a light thumb press.** Location still comes from the 4
     column screws, not the walls.

   OUT of tolerance is: needing tooling or a clamp, or the servo case galling
   rather than sliding. Free-falling to the floor is not a pass either — it
   means the ribs are missing or short.

   (0.30/side = the v5 press-fit calibration — do NOT "fix" it back. And do
   not "fix" the 0.10 mm either: the ribs are meant to interfere; the thin
   tip crushes to take up print tolerance and carry torque.)

   ⬜ **First article, record it:** does the RIB crush, or does the servo CASE
   score? The ribs are PA6-CF against a much softer case, so scoring is the
   likely outcome and is cosmetic — but `servo_pocket_analysis.py`'s wall-
   bearing claim assumes the rib profile SURVIVES, so the answer changes that
   analysis. Also check the seated servo for any rock about Z, which is the
   failure the ribs exist to prevent.
2. Knee-arm plate: seats flat on the shelf, diagonal Ø3.1 screws register
   snugly BEFORE the clearance pair; horn face flush under the plate ±0.2.
3. **M3** countersink flush (heads must NOT proud into the yoke arm plane).
   Use **button** heads on the wheel ×8/×14: an M3 SHCS head stands ~1.4 mm
   proud of the 1.6 mm counterbore, a button ~0.05 mm.
4. Heat-set **bore Ø4.0** — check insert purchase in PA6-CF at 5.7 deep. The **4.6 is the
   INSERT OD**, not the bore; `HEATSET_D = 4.0` in `leg_v6_common.scad` and a **Ø4.6 bore
   drops straight through** (row 14 of the fastener table above says exactly this, and calls
   it an audit catch — this line had reproduced the error the table was written to prevent).
   ⚠️ Two different inserts exist by design: **4.6 OD × 5.7 everywhere** (ruthex
   `B08BCRZZS3`) and **4.0 OD × 6.0 slim for the HFE block ONLY** (uxcell `B07R9SP532`) —
   the slim one is NOT a substitute in a Ø4.0 bore, where it would have zero interference.
5. Yoke gap: tibia end floats with 0.2-0.6 play. PA6-CF shrinks 0.2-0.8% —
   if the gap CLAMPS the discs, sand the arm faces or reprint at +0.3% Z.

## Build
```bash
/opt/homebrew/bin/openscad -o femur_v6.stl femur.scad
/opt/homebrew/bin/openscad -o /tmp/fit.png --imgsize=1000,650 \
  --camera=55,0,-2,60,0,25,330 preview_femur_fit.scad   # ghost-servo fit view
```

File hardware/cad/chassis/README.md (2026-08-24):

# Chassis — trunk riser bay (+ Jetson case + integrated head: D456 + L2)

> Top-level design: [`docs/design-outline.md`](../../../docs/design-outline.md)
> · trunk mate dims: [`../dimensions.md`](../dimensions.md) §11 · reasoning:
> `~/claude-memory/nova-proj/project-chassis-integration.md`

Started 2026-07-06. First chassis-lane part: the printed **riser bay** that
replaces the stock trunk lid — its top IS the Jetson tray and the L2 mast
base (design-outline packaging). OpenSCAD + real-mesh fit gate, per leg_v6
doctrine (the cad/README's "OnShape for chassis" note predates leg_v6; this
lane follows the leg_v6 track).

## What the trunk ACTUALLY is (mesh-measured 2026-07-06, `measure_trunk.py`)

The "~118 × 100 × 40 interior tub" assumption was WRONG. The stock
`SM3_Frame_ChassisTrunk.stl` (127 × 110 × 46.91, floor z0, +x = the printed
"F" arrow) is an open frame:

| Feature | Measured |
|---|---|
| floor slab | top z 3.9; big rear opening + corner cutouts (cable/battery pass) |
| side walls | 6.0 thick, inner y ±48.93, **top z 29.0**, notch x 18.2..31.2 → z 12.5 (both) |
| ends | **OPEN above the floor** — closed at assembly by the v6 shoulder flanges |
| corner wedges | 4× leaning slabs (~35°) rising wall-top→plateau; **plateau tabs z 46.91**, x ±(53.3..63.5), y ±(29.9..36.0) |
| wedge windows | ~9.4 × 6.4 under each plateau tab (stock cover hooks; unused by us) |
| shoulder bolt bores | Ø3.16 along x at (y ±51.75, z 5 & 24), 6.5 deep, both ends — matches `shoulder.scad` |
| interior clear width | 97.86 (stack 90 fits, 3.9/side) |

## Parts

| Part | Status | Notes |
|---|---|---|
| `riser_bay.scad` | designed, gated | one print, 126.7 × 110 × 42.9 (z 29.0..71.9). **Reworked 2026-07-07 for the case pivot**: dropped the 96.5×75.4 Jetson standoff grid + all hood pads/inserts; added the case PORT-END cable slot (x −58..−46, y ±18 = also the case bottom-vent breather), 4 cradle deck ties (47.3/−59.0, ±50.35). **Head interface RETIRED 2026-07-07** — the L2-column deck base, L2 cable drop, front-wall camera register + USB grommet removed (head moved fwd onto `neck_bracket.scad`); **SMA bulkheads also removed** — WiFi MIMO antennas consolidated to the head ears (higher, clear of the CF chassis) |
| `spacer.scad` | **RETIRED** | Jetson standoff washers — unused now the board is in the official case (kept in build_all for reference) |
| `trunk.scad` / `trunk_build.py` | **designed, gated (2026-07-10)** | **DERIVED TRUNK** — stock Nova-SM3 trunk geometry (unmodified, imported) + 10 MODELED fastener bores (battery mount ×6, shoulder-foot CSK ×4) so nothing is drilled at assembly; the shoulder-flange end-wall bores (×8) turned out to be already-stock (measured), no cut needed. Shipped `trunk.stl` is built by `trunk_build.py` (trimesh + manifold3d) — see its docstring for why, not the OpenSCAD render (a pre-existing, hole-unrelated mesh-tessellation quirk in the stock STL fails a strict watertight re-check under either engine; `check_fit.py`'s own in-memory asserts are the real gate). `check_fit.py` case 13 verifies every hole sits on its mating part's bolt axis |
| `battery_pocket.scad` | designed, gated | rear-loading belly tray, 6× M3 sandwich mount through the floor (**part-5 plate must adopt the (±40/0, ±26.5) pattern**; hole now MODELED in `trunk.scad`, no drilling), velcro fence at the rear opening |
| `head.scad` | **RE-ARCHITECTED + gated (2026-07-07)** | **forward HEAD on the front-shoulder "neck"** — moved OFF the riser front and FORWARD onto the front-shoulder top so it projects ahead like a fox (not a turret). Bolts to `neck_bracket.scad`, NOT the riser. Sensors shifted **DX+73 DZ+6** vs the old riser head (`forward_head_study.py` = the proof): D456 27° down-tilted face, back-face ctr **(143,0,111.5)**, body x136.4..172.7 z86.8..124.4 y±61.9; L2 crown center **x126.5**, optical z~160, seat 128. Camera bottom clears the front horn-plate top (+2.0) + the bracket base (+3.25); camera top +3.6 under the L2. **0 front-leg hits** across the full ROM. Mounts via a rear boss → 4× M3 into the bracket wall (tall couple). L2 = 4 crown screws from below; camera bolts on the bench. **Right-angle USB-C** (BOM). Print BOSS-DOWN. STYLE (fennec ears/skull) = WIP, default off |
| `neck_bracket.scad` | **designed, gated (2026-07-07)** | **front-shoulder-deck adapter** for the fwd head (user call: separate bracket, keeps the shoulder gate-clean + print-2-identical, head stays removable). Base plate on the deck top (z79.55); **4 corner bolts drill THROUGH the deck at first assembly** (M3 + nyloc below, reached through the deck window + open aperture — NO shoulder-mesh change). Tall rear mount wall (x113..121, to z106) with 4× M3 heat-sets (rows z89/100) = the head-mount face; aft gusset + base-bolt couple react the forward-tipping moment. Cable slot over the deck window (L2 pigtail → C-box → trunk). Print base-down, PA6-CF |
| ~~`l2_mast.scad`~~ **RETIRED** | → `head.scad` | standalone L2 mast; folded into the head crown. File kept (RETIRED header) for its reused bore/flange/bolt knowledge; not built, not gated |
| ~~`d456_head.scad`~~ **RETIRED** | → `head.scad` | v3 periscope; tilted the D456 UP behind the chassis and the trunk front cut its near-ground view. File kept (RETIRED header) for its D456 2×M3@94.4 mount + USB-C routing knowledge; not built, not gated |
| `../leg_v6/shoulder.scad` | **rev'd ×4** | + center notch (x ±26 above z 19.5) + 2× Ø3.4 riser holes (x ±40, z 29.35) + **battery-lead bottom notch** (x ±10 to z −26 = trunk z 12) + **flange floor FEET + deck gussets** (2026-07-06 joint-stiffening, user catch "barely connected": feet bolt the flange bottom to the trunk floor corners at (±59.5, ±42) — M3×14 csk from BELOW, hole now MODELED in `trunk.scad` (no drilling; **DONE 2026-07-10** — was the floor_plate drill template); gussets flange→deck-ext at x ±40); leg_v6 + chassis gates re-run (new shoulder-vs-trunk case in check_fit) |
| `floor_plate.scad` | designed, gated | 2.0 plate = mezzanine seat (top 5.9) + battery-sandwich csk pattern + **drill template** for all 10 floor holes; stack pilots at (−40.5/+33.5, ±33) from the power_v2 fab file (74×66); **stack ctr x −3.5** (rear edge 0.5 off the trunk corner posts, front corners clear the front slabs by 0.8) → rear-only slab trim + CoM −3.5; corner clips for the post base flare; front edge x 45 clears the raised stock "F". **5191 slots REMOVED 2026-07-07** — the calipered block is 61.6×20×46.5 and there is NO clean captive spot on the robot for it (below = leg-crouch space, rear-center = shoulder flange, trunk interior = mezzanine stack; all gate-verified conflicts). **5191 = ASSEMBLY-TIME external mount** (bracket/zip-tie to the rear-shoulder exterior or trunk rear, found empirically with real parts; fuse close to the battery-lead entry). Leads: pack rear → up through the rear shoulder flange notch |
| `skid_rail.scad` | designed, gated | TPU 95A belly skids ×2 (backlog #15): keyed+glued under the tray, new lowest z −42.2; E-stop-limp collapse lands HERE, not on the pack. Inboard-haa 15° cap verified intact with rails in the crouch gate |
| ~~tray hood~~ **RETIRED** | — | Jetson heatsink CALIPERED 34.9 (not 21.5) → heatsink top 113.1 collides the L2 plate. **DECISION 2026-07-07 (user): adopt the OFFICIAL JETSON CASE** (110.5×95.2×38.5, `jetson_case_ref.stl`) instead of the bespoke tray+hood. Case on the deck → top 110.4, clears L2 by 4. Drops the hood; E-stop pod + OLED move off the hood (new homes TBD). Repackaging in progress: case cradle mount + L2/D456/SMA refit |
| `jetson_case_mount.scad` | **designed, gated** (`check_fit.py` case 12) | deck cradle + corner hold-downs for the official case (bottom is vented — mount via 4 drilled corners); riser deck reworked (old Jetson standoffs + hood pads removed). Hold-down consolidated into `jetson_clamp_bar.scad` (2 bars, replaced 4 corner clamps) |

## Riser design (all trunk-frame numbers)

- **Seat**: side skirts (3.2, outer flush y ±55) rest ON the wall tops
  (z 29.0) — two full-length rails = primary datum. End walls (x ±60.15..63.35)
  stop 0.1 above the wedge plateaus. Lateral register: 4 tabs inside the wall
  inner faces at x ±40 (0.45 clearance, drop-in doctrine).
- **Hold-down (NO stock-shell mods)**: 4× **M3×12** horizontal through the
  shoulder flanges into heat-set pads in the riser end walls at (y ±40,
  z 67.4 — the end-wall pad band z 64.4..70.4 sits above the stack envelope
  and fuses into the deck; a z-65-centered pad protruded into the stack
  corners, gate catch). Inserts press from the pad's INNER face (from
  below, pre-mount) so screw tension seats them deeper — outer-face press
  was extraction-loaded (design-review fix).
  Fore-aft location = these screws (±0.15), leg-doctrine style. The riser is
  NEVER structural.
- **Deck top z 71.9** (= trunk top + 25, outline-locked) and FLAT: every
  fixture is an underslung boss → prints deck-face-down, zero supports.
- **Jetson Orin Nano devkit**: grid 96.5 × 75.4 at bores
  (−58.25/+38.25, −47.4/+28.0); carrier spans x −60..+40, y −49.4..+30,
  **ports face +y**, plugs drop through the deck slot (x −53..−44, y 26..46).
  Rear fin + mast stay clear of the plug row. Board plane z 78.2
  (6.3 spacers, **M3×14** — ×16 grazes the stack envelope, ×12 only bites
  3.2mm).
- **HEAD MOUNT — RE-ARCHITECTED 2026-07-07**: the head no longer bolts to the
  riser. It moved FORWARD onto the front-shoulder top (the "neck") via the
  separate `neck_bracket.scad`, so it projects ahead like a fox. The riser
  front head features below (deck L2-column base, front-wall camera register,
  USB grommet) are now **ORPHANED** — pending retire (a riser re-cut + re-gate).
  - **neck bracket → shoulder deck**: base plate on the deck top (z79.55), 4
    corner bolts drilled THROUGH the deck at first assembly (M3 + nyloc below).
    No shoulder-mesh change → shoulder stays gate-clean + print-2-identical.
  - **head → bracket**: a rear boss takes 4× M3 into the bracket's tall wall
    (rows z89/100) — a tall couple vs the forward-tipping moment. Cables drop
    the neck cable slot → deck window → shoulder C-box → trunk.

  Head removal = the 4 boss→bracket bolts → lifts off with the L2 + camera. The
  bracket stays bolted to the deck (drilled once), so the head is a modular
  removable unit for fennec-styling iteration.
- **SMA bulkheads**: REMOVED 2026-07-07 → the 2× WiFi MIMO antennas now live
  in the **head ears** (Ø6.5 SMA bores, higher + clear of the CF chassis). ⚠
  antennas are a PROVISION only — onboard Jetson WiFi works; test bench range
  first, then order (2× SMA bulkhead + 2× U.FL→SMA pigtail + 2× whip, ~$25) and
  verify the WiFi card exposes U.FL.
- ~~**Hood interface**: 4× M3 horizontal heat-sets in the side walls at
  (x −50/+35, z 67)~~ **GONE 2026-07-07** — the hood is retired and
  `riser_bay.scad:34` records these pads as removed. (The M3 heat-sets that
  DO survive at z 67.4 are the riser↔shoulder-flange pads at y ±40 — a
  different fixture; see `riser_bay.scad:70`.)
- **Vents**: 6× 3 mm slots per side, **TWO rows** — upper z 52..66 (logic
  level) and LOW z 33..45, added on thermal review because the under-board
  buck pocket (z 6..22) had zero airflow.

## Battery pocket (`battery_pocket.scad`, trunk-frame numbers)

- Open-top tray under the shell (shell floor caps it); rim at z −0.2, tray
  bottom −39.2; cavity 156.6 × 47.6 × 35.8 (pack + 0.8/side, **listing dims
  — caliper the real pack at first article**). Pack overhangs the trunk
  ~14.8/end, 0.25 under the shoulder flange bottoms.
- Rear-loading: pack slides in from −x; velcro strap wraps the pack's REAR
  CORNER (slots at x −77..−61 — direct tension against slide-out, not
  friction; design-review fix; shake-test at first article). Battery swap =
  strap only, 0 tools.
- Mount: 6× M3×12 from inside the trunk through the 3.9 floor into
  full-height boss columns at (x ±40/0, y ±26.5) with side-loaded **M3 nut
  traps** at z −8.2 (review fix: printable columns + a nut beats an insert
  at the pocket's highest-load joint). Floor gets a **modeled Ø3.4
  clearance hole** there (`trunk.scad`/`trunk_build.py`, 2026-07-10 —
  printed in, no drilling; the part-5 plate adopts the same pattern)
  (screw sandwich: plate + floor + tray).
- Leads: exit the pack rear face behind the trunk end, rise at x ~−70,
  enter through the **shoulder flange bottom notch** (y ±10 to z 12) to the
  MRBF-30 / 5191 block inside (block mount = part-5, ⚠ dims unmeasured).
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

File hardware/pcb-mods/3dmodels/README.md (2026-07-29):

# 3dmodels — render-only 3D models

Models referenced by `(model ...)` entries in the v6 board files so
`kicad-cli pcb render` shows populated boards. **No electrical meaning.**

- `Teensy_4.1_Headers.step` — real colored Teensy 4.1 model (GrabCAD
  community, from Aiden's Downloads snapshot). Used on the logic board:
  rotate z 90, offset (0, 0, 3.3) — header plastic bottom (internal z -3.3) seats on the board; uncut pins protrude ~4.6mm below (model z spans -9.5..+9.5, PCB at ±0.8). Supersedes `Teensy_4.1.wrl` (kept as fallback).
- `Arduino_Nano_Classic.step` — real classic Nano (user-supplied GrabCAD,
  MEGA328P). Aux-MCU slot: offset (0, 0, 9.5), rotate (-90, 0, 90) — model
  authored on its side, USB toward -x internally. Paired with 2x KiCad
  `PinSocket_1x15_P2.54mm_Vertical.step` at offsets (0,0,0)/(15.24,0,0)
  so the 8.5mm socket height reads as a socketed module.
- `arduino_nano_r4.step` — step.parts catalog (checksum-verified). Unused
  alternate (modern Nano R4).
- `Arduino_Nano.wrl` — placeholder in the `Module:Arduino_Nano` lib frame
  (pin1 at origin). KiCad 9 ships no Nano STEP.
- `INA226_Module.wrl` — CJMCU-226-style module slab; positioned for the
  `nova_v6:INA226_Module_Breakout` footprint. U12 is DNP (Phase-4 arm rail)
  and correctly renders unpopulated.
- `Teensy_4.1_Assembly.STEP` — XenGi/teensy.pretty original; unused
  (multi-part assembly, off-center bbox). Kept for reference.

XT30s: real XT30-M STEP (`XT30-M.step`, user-supplied GrabCAD model).
Model pins at internal (0,3)/(0,8) along +y -> rotate z 90, offset x -3
(standalone lib footprints) or (-5.5, ±5) (buck stations). Earlier
scaled-XT60 substitution retired.

Patch script (idempotent, re-runnable): `patch_models.py` in this folder;
re-run it to re-add entries if footprints are ever re-imported.

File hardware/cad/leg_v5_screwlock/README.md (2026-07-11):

# Leg V5 — Screw-Lock variant

> ⚠️ **SUPERSEDED by [`../leg_v6/`](../leg_v6/README.md) (2026-07-02)** — the added
> screws threaded into what turned out to be the horn/wheel disc pattern, not
> case threads (see leg_v6 rev-2 notes). Historical only.

Copy of `../leg_v5/` (coax, femur, tibia) that adds the **screw features the
canonical cavity lacks**, so the STS3215 can be bolted in and locked instead of
relying on the press-fit pocket alone. Originals in `../leg_v5/` are untouched.

Built 2026-06-06.

## What changed vs leg_v5

| Part | leg_v5 | here |
|---|---|---|
| coax (L/R) | servo cavity only | cavity **+ 4× M2.5 case mount holes** |
| femur shell + cover (L/R) | cavity only | cavity **+ 4× M2.5 case mount holes** (shell + cover share them via `femur_params.scad`) |
| tibia (L/R) | passive, no cut | passive by default; **4× M2.5 horn-coupling pattern** behind a `HORN` flag (mate face not yet measured) |

The outer shape and the existing `CAVITY_CENTER` / `CAVITY_ROT` placements are
copied verbatim — only screw holes are added.

## The hole pattern is STEP-extracted, not guessed

`sts3215_mount.scad` pulls the case mounting pattern straight from the servo
STEP (`feetech_servo_models/.../STS3215_03a v1.step`): the 18 Ø2.5 circles
resolve to a **9.9 × 9.9 mm square** of M2.5 holes, centered on the spline axis,
on each shaft-normal face:

```
(x, y) = {7.55, 17.45} × {-4.95, +4.95}   [cavity-local frame: long=X, width=Y, shaft=Z, spline at +X 12.5]
```

`sts3215_mount_holes()` cuts full-through Ø2.9 (M2.5 clearance) columns at those
4 positions, riding the same `translate(CAVITY_CENTER) rotate(CAVITY_ROT)` as
the cavity.

### Which face to screw

- **Top (+Z, horn side):** holes sit at R≈7 from the spline, inside the Ø20 horn
  disc / Ø21 relief — **not usable** for body mounting (those ends land in
  already-void relief, harmless).
- **Bottom (−Z, back-shaft side):** clear of the Ø6 back-shaft relief. In coax +
  femur this face backs into solid leg material, so a screw through the leg wall
  threads into the servo case and clamps the body. **This is the mounting face.**
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

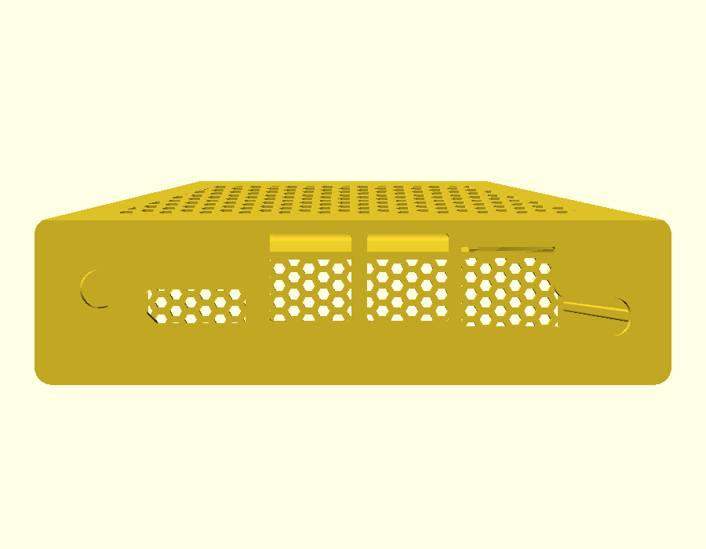
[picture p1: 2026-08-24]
hardware/cad/chassis/renders/jetson_case_ref_front.png

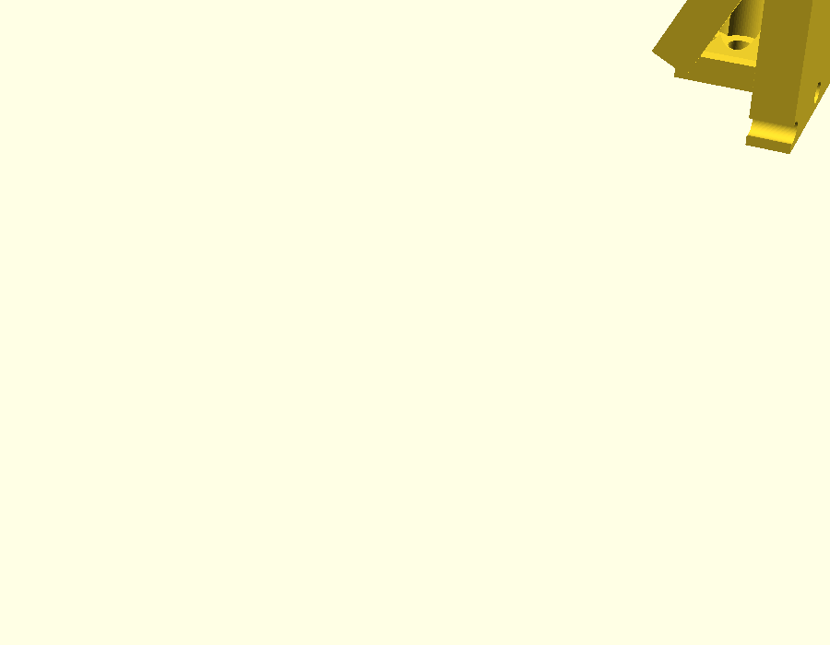
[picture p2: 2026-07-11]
hardware/cad/chassis/renders/head_iso.png

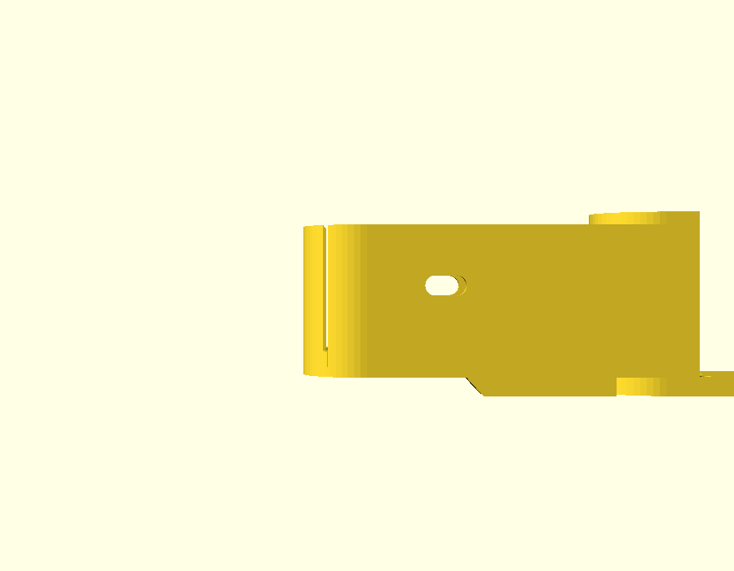
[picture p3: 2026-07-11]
hardware/cad/leg_v6/renders/femur_R_front.png

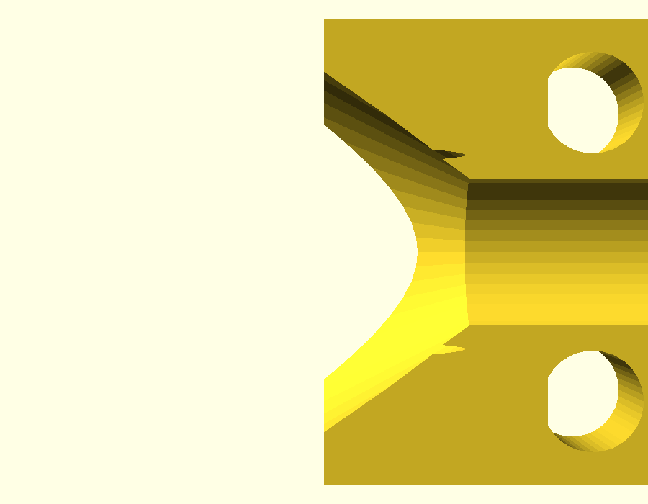
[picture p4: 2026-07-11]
hardware/cad/leg_v6/renders/cable_clip_top.png

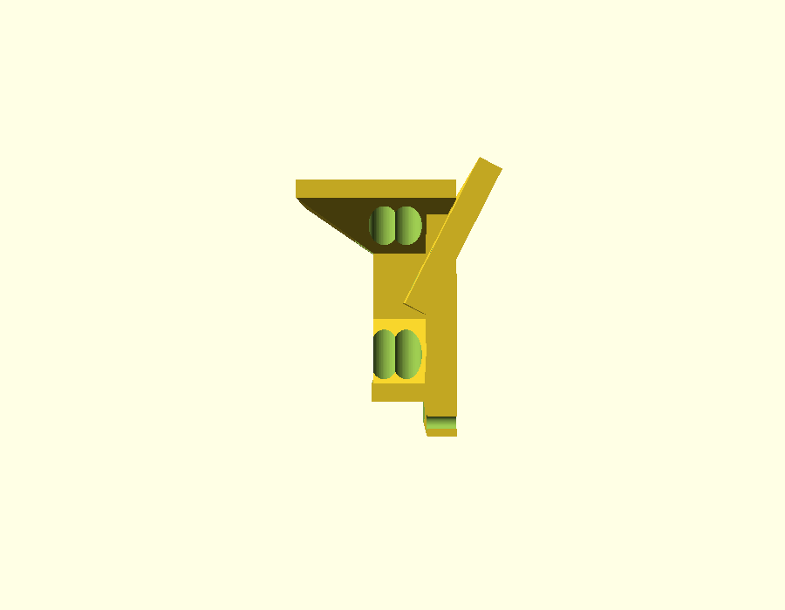
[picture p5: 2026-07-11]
hardware/cad/chassis/renders/head_side2.png

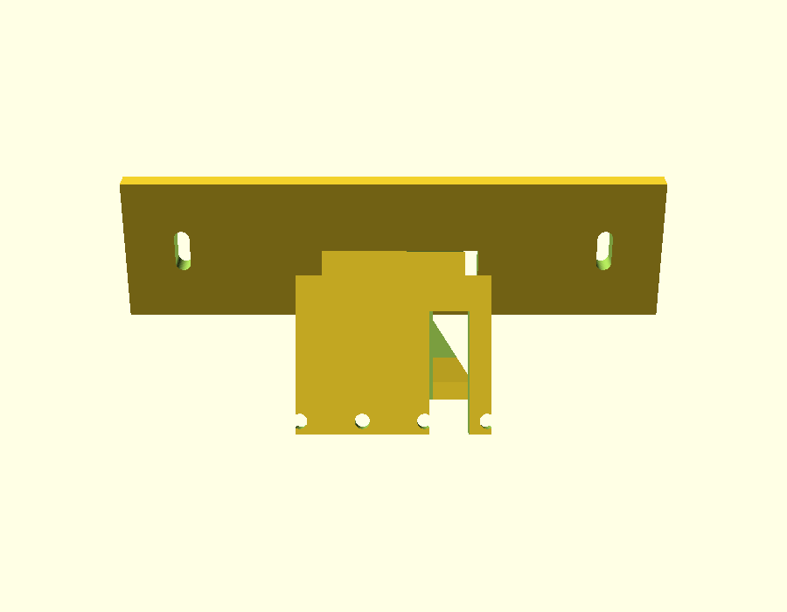
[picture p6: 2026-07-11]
hardware/cad/chassis/renders/head_front2.png

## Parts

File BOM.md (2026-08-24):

# NovaSM3 Quadruped Build — BOM v3.4 (Committed)

**Last updated:** May 16, 2026
**Supersedes:** BOM v3.3
**Status:** v1 scope narrowed to **quadruped only** (12 servos active). Arm (6 STS3215) demoted to Phase 4 future work; bus IDs 13-18 + arm-rail buck footprint reserved on PCB redesign. Power rails redesigned around Pololu modules after XL4016 capacity audit. v3.4 split L2 LiDAR off the hip rail onto a dedicated D24V22F12 buck — combined hip+L2 load was margin-thin at the F12's 9A typ @ 42V Vin (derates further at 14.8V). Full safety scope: LVC alarm + E-stop + INA226 per-rail telemetry + MOSFET hard-cutoff. **Bus master: Pattern B is v1 default** — Teensy 4.1 UART → SN74LVC125A half-duplex driver → bus. Pattern A (FE-URT-1 → bus) kept as bench/debug fallback via solder bridge.

---

## 1. Compute + Perception

| Item | Price | Status |
|---|---|---|
| Unitree L2 3D LiDAR | $451 | ✅ Ordered (DLZ-3974) |
| NVIDIA Jetson Orin Nano Super Dev Kit 8GB | $249 | ✅ Owned |
| Intel RealSense D456 | $584 | ✅ Ordered (#000187781) |
| WiFi/BT module | $0 | ✅ Included — Jetson Orin Nano Super Dev Kit (P3766) ships with 802.11ac/abgn WiFi pre-installed per official spec. WiFi 5 (ac), **not** WiFi 6E. BT not explicitly listed in spec — verify on arrival. If somehow missing, order AX210NGW + U.FL antennas separately (~$30). |
| ~~DisplayPort cable / DP→HDMI adapter~~ | ~~$10~~ | ❌ Not needed — Jetson set up headless via SSH 2026-05-21 |
| LeRobot Pi's 128GB Amazon Basics microSD | $0 | ✅ Reuse — back up LeRobot configs first. **128GB enough for Phase 1-2.** NVMe migration deferred until NAND prices recover or storage becomes a measured bottleneck. |

**Compute subtotal of new adds: $10**

> **NVMe deferred (May 2026):** AI-data-center-driven NAND flash shortage has 2-3x'd consumer SSD prices. 1TB Crucial P3 Plus that quoted $60-80 in early 2026 is now $165-220 retail. Kingston: NAND wafer costs +246% since 2024. TrendForce: client SSD +40% QoQ in Q1 2026. Relief not expected until late 2026 / 2027-2028. See Deferred section for revisit triggers.

---

## 2. Control + Electronics

| Item | Price | Status |
|---|---|---|
| Teensy 4.1 (with pins) | $50 | ✅ Owned |
| Arduino Nano (ELEGOO 3-pack, CH340) | $15 | ✅ Ordered |
| ~~NovaSM3 PCB v5.2b~~ → **NovaSM3 PCB v6 — 2-board mezzanine** (power + logic, 4-layer each) | $60 (est.) | 🆕 Design + order from PCBWay — **two stacked PCBs**: power board (`nova_pcb_v6_power`: battery / rails / servo-bus / safety) + logic board (`nova_pcb_v6_logic`: Teensy / SN74LVC125A / Nano), joined by the inter-board connector below. Both 4-layer, ~112×90 max. See [`hardware/pcb-mods/README.md`](../hardware/pcb-mods/README.md). |
| **Inter-board connector (mezzanine J20)** — 2× 2×6 shrouded box header (2.54 mm THT) + 12-way IDC ribbon | $4 | 🆕 Order — joins power↔logic across the ~20 mm stack gap. Box-header pair + ribbon, **NOT plain pin headers** (two males can't mate; a 0.1″ header can't span the gap). Carries 7 nets: V5_AUX, +3V3, BUS_SERVO, I2C_SDA/SCL, BATT_LOW, GND. |
| FE-URT-1 USB→TTL Feetech interface | $20 | ✅ Ordered |
| **SN74LVC125A quad tri-state buffer** (Pattern B half-duplex driver) | $1 | 🆕 Order — **must be LVC (5V-tolerant), NOT plain 74HC125**. Populated on PCB; v1 default active. Drives the Feetech bus from Teensy 4.1 UART. Solder bridge `JP_BUS_MASTER` defaults to B; flip to A only for bench bring-up or debug fallback via FE-URT-1. Buy 5 (cheap, easy to fry). |
| **E-stop button (Mxuteuk HB2-ES544, 22mm latching, 2× NC)** | $10 | ✅ Ordered |
| **INA226 current/voltage monitor × 3** | $9 | 🆕 Order — one per active rail (leg 7.5V, hip 12V, Jetson 12V). **All 3 as identical 2 mΩ breakout modules** (THT headers; module onboard shunt — no bare VSSOP-10 chip / external 2512 shunt). Must be a 2 mΩ board; 0.1 Ω "meter" modules saturate >0.8 A. Optional 4th on L2 12V rail if telemetry budget allows. I²C to Teensy. |
| **Comparator + MOSFET parts for hard-cutoff at 12.4V + graceful-shutdown at 13.0V** | $13 | 🆕 Order — two comparator stages. 13.0V: drives Teensy GPIO → Jetson clean shutdown. 12.4V: autonomous battery-feed cutoff if Jetson didn't shut down. ~$3 extra for the second comparator + divider. |

**Feetech bus architecture: Pattern B is v1 default.**
- **Pattern B (v1 active):** Teensy 4.1 hardware UART → SN74LVC125A half-duplex driver → 12-servo TTL bus. Bare-metal real-time. Jetson sends joint targets via micro-ROS over USB; Teensy translates to bus writes at 200-500 Hz. Survives Jetson restarts, kernel preemption, CUDA stalls, journald flushes — none of which affect bus servicing. Solder bridge `JP_BUS_MASTER` defaults to B.
- **Pattern A (bench / debug fallback):** FE-URT-1 → USB → Jetson directly drives the bus. Flip `JP_BUS_MASTER` to A for: initial servo ID assignment from a workstation (before Teensy firmware is ready), debug if Teensy firmware misbehaves, or post-mortem inspection of bus traffic. Not the runtime path.

Why B as default (revised from v3.2): Linux is not a real-time OS. USB-CDC latency on Jetson is 1-10 ms typical, 50 ms+ under load (CUDA kernel preemption, kworker spikes). What Pattern B actually buys: **bus servicing is isolated from Linux jitter** — the Teensy guarantees its UART transactions complete on time so individual servo writes/reads don't time out and the bus doesn't error-out from late ACKs. The gait controller still runs on Jetson and publishes targets at 100 Hz, so Jetson's command rate is still Linux-bounded; but the Teensy oversamples at 200-500 Hz against the *last received* target, holding it through Jetson stalls. A 100 ms Linux freeze becomes "robot pauses mid-step" not "bus dies and robot falls." Defaulting to A would force a measure-then-migrate decision in Phase 1; defaulting to B skips that for one $1 IC + Phase 1 firmware work.

Cost of Pattern B as default: SN74LVC125A must be populated (~$1, already in §2 above) + Teensy firmware becomes a Phase 1 critical-path deliverable (was a Phase 2+ stub).

---

## 3. Power

### Main power chain (Pololu redesign)

XL4016 ×2 dropped from active design after capacity audit: 8A continuous rating is insufficient for walking-gait current (8-12A avg, 25-40A impact transients per leg-rail load profile). See [`docs/power-budget.md`](../docs/power-budget.md) for math. XL4016 boards stay in spares bin for low-current aux duty.

| Item | Price | Status |
|---|---|---|
| 4S LiPo 14.8V 6000mAh 120C (×2, Ovonic) | $130 | ✅ Owned |
| XT60 plug + high-current switch | $15 | ✅ Ordered |
| Lighted rocker switch 12V | $5 | ✅ Ordered |
| Mini digital voltmeter | $10 | ✅ Ordered |
| ~~XL4016 12A buck (×2)~~ | $0 | ↩️ **Returned for refund 2026-05-18** (8A cont. inadequate for walking-gait + impact transients; superseded by Pololu D42V110-class). $30 recovered. |
| XL6009 buck-boost | $10 | ✅ Owned — spare, no allocated role |
| **Pololu D42V110F7 — 7.5V leg rail (10A typ @ 42V Vin)** | **$60** | 🆕 Order. Output 7.5V (within STS3215 6-8.4V range). 12-60V Vin range — actually 7.6V min Vin per page. Drives 8× femur/tibia STS3215 (19kg). Derates at our 14.8V Vin; bulk caps at 4 star injection points absorb 25-40A impact transients. |
| **Pololu D42V110F12 — 12V hip-only rail (9A typ @ 42V Vin)** | **$60** | 🆕 Order. Drives 4× hip STS3215 (30kg) **only** — L2 LiDAR moved to dedicated buck below to leave headroom (rail margin was sub-1× under combined load at 14.8V Vin). 12-60V Vin. |
| **Pololu D24V22F12 — 12V dedicated L2 LiDAR rail** | **$19** | 🆕 Order. New in v3.4 (Option A split). 36V Vin max. ⚠️ **CURRENT RATING DISPUTED 2026-08-18:** this row said "2.6A max ... ~2.6× headroom", but Pololu's own spec page (item 2855) states **1.9 A at 24 V in**. The L2's ~1 A still fits either way, but the stated headroom does not follow from the vendor's number — reconcile before relying on it. Size is now Pololu-sourced too: **17.78 × 17.78 × 7.87 mm**, correcting the 6.0 height in dimensions.md (see #366). Clean power for LiDAR — no servo transient ringing. LC filter retained on the L2-buck output. |
| **Pololu D42V55F12 — 12V Jetson rail** | **$32** | 🆕 Order — replaces deprecated D24V50F12. Derates to ~3A cont. at 14.8V Vin → ~1.4× headroom over Jetson MAXN 2.1A. Min Vin 12V → **LVC alarm at 13.2V**. Reverse-polarity protected. Find via Pololu D42V55Fx family page → 12V variant. |
| **Pololu D42V55F7 — 7.5V arm rail (future)** | **$0** | ⚠️ **Footprint reserved on PCB v6; don't populate until Phase 4 arm install.** Output 7.5V (within STS3215 6-8.4V range). Estimated cost when ordered: ~$32. |
| UBEC 5V/5A | $15 | ✅ Owned — 5V peripherals (fans, aux sensors) |
| Bulk caps for rail injection points (1000 µF / 25V × 5, **low-profile Ø12.5×16 mm radial**) | $5 | 🆕 Order with electronics — soaks servo impact transients near point of load. 5 points: 4× leg (J3-J6 V7V5_LEG) + 1× hip (J7 V12_HIP). **Height-reduced** (16 mm tall vs 20-26 mm standard; Ø12.5 unchanged) to fit the 46.9 mm mezzanine stack. E.g. Rubycon `25ZLH1000MEFC12.5X16`. Footprint `CP_Radial_D12.5mm_P5.00mm` (diameter unchanged → footprint unchanged). |
| PCB terminals + misc boards | $8 | ✅ Ordered |
| Dip switches + resistors + buttons | $8 | ✅ Ordered |

### Battery charging + safety

| Item | Price | Status |
|---|---|---|
| **ISDT 608AC charger** | **$60** | ✅ Ordered. AC mode caps ~55W ≈ 110 min for 4S 6000mAh pack. Includes charge / discharge / **storage** modes. |
| **LiPo safe bag** | **$15** | ✅ Ordered. |
| ~~XT60 jumper~~ | $0 | ✅ Supplied with Ovonic 4S kit (confirmed) |
| ~~XT60 charging lead~~ | $0 | ✅ Supplied with Ovonic 4S kit (confirmed, XT60 ↔ JST-XH 5-pin balance) |

### Final power rail map (v3.4)

```
4S LiPo (12.8-16.8V) ──┬── Pololu D42V110F7  → 7.5V/10A → 8× femur/tibia STS3215 (19kg)
                       │                                  ↑ star injection: 4 points across chain
                       │
                       ├── Pololu D42V110F12 → 12V/9A   → 4× hip STS3215 (30kg) ONLY
                       │
                       ├── Pololu D24V22F12  → 12V/2.6A → Unitree L2 LiDAR (LC filter on output)
                       │
                       ├── Pololu D42V55F12  → 12V/~3A  → Jetson barrel jack
                       │
                       ├── [reserved arm rail]           → 7.5V/3-8A → 6× arm STS3215 (Phase 4)
                       │   (D42V55F7 footprint, unstuffed)
                       │
                       └── UBEC 5V/5A        → 5V       → fans, aux 5V peripherals
```

**Power tree safety chain (ordered by trip point, highest pack voltage first):**
- 608AC charger LVC alarm: **3.3V/cell = 13.2V** pack (warning beep; user response)
- Graceful-shutdown comparator: **3.25V/cell = 13.0V** pack → drives Teensy GPIO → publishes `/battery_low` → Jetson runs `systemctl poweroff` (allows clean SD card unmount before the hard cutoff fires). ~30-60 s window between this and the hard cutoff at typical discharge rates.
- MOSFET hard-cutoff: **3.1V/cell = 12.4V** pack (autonomous backstop, comparator-driven, breaks main battery feed). Drops everything including Jetson — but Jetson should have already shut down cleanly per the 13.0V line above.
- Panel-mount E-stop: NC contact in series with the **servo-rail + L2-rail enable lines** — kills D42V110F7 + D42V110F12 + D24V22F12 outputs (LiDAR stops spinning); Jetson rail stays live for debug + telemetry post-mortem
- INA226 per active rail (3-4×): I²C → Teensy → ROS 2 diagnostics topic. Leg, hip, Jetson rails mandatory; L2 buck optional 4th if telemetry budget allows.
- **MRBF-30 terminal fuse on battery feed — mounted OFF-board** (Blue Sea 5191 block at the pack, not on the PCB; F1 removed from `nova_pcb_v6` 2026-06-04). 30A time-delay, sized for hip-rail peak ~20A + headroom. ANL was originally specced but its 6 kA interrupt rating can fail-to-interrupt a LiPo dead-short → rejected. Class T (20 kA) was the interim choice, but this single 4S pack's real Isc ≈ 16.8 V ÷ 6–12 mΩ ≈ **1.5–3 kA**, vs MRBF's **~9 kA AIC @ 16.8 V = 3–4× margin** at ⅓ the size/weight → **MRBF chosen 2026-06-12**. At-source placement also protects the battery→PCB cable. ~$24 block + ~$10 fuse. Install: battery XT60 pigtail → 10 AWG ring → 5191 stud → MRBF-30 → output ring → J1 lead. See [`docs/order-list.md`](docs/order-list.md) MRBF section + [`docs/research/2026-05-17-notes.md`](docs/research/2026-05-17-notes.md) §9.

---

## 4. Servos (Feetech TTL Unified Bus)

**v1 scope: 12 active servos** (4 hip + 8 femur/tibia). Arm (6× STS3215) deferred to Phase 4 — kept on shelf, bus IDs 13-18 reserved, arm-rail PCB footprint reserved.

> **Naming — STS3215 = ST3215 (same part).** The BOM says "STS3215" (Feetech's
> name for the magnetic-encoder serial-bus servo); the hardware on hand is
> Waveshare-branded **"ST3215"** — Feetech is the OEM, Waveshare rebadges it.
> Same servo. Don't order a different part when a listing says "ST3215".
>
> **Variant: standard C001, 1:345 gear** (bench-confirmed 2026-07-14 — no-load
> speed matches 1:345, not the faster low-torque **ST3215-HS**; same variant as
> the SO-ARM101 arm servos). One servo, torque/speed set by rail voltage:
> **19.5 kg·cm @7.4V** (legs, 1.91 N·m) / **30 kg·cm @12V** (hips, 2.94 N·m);
> no-load 45 RPM @12V (4.71 rad/s), ~2.8 rad/s @7.5V; 6–12.6 V; 4096-count
> magnetic encoder on the output shaft; **60 g measured** (datasheet 69 g incl
> horn+cable). Full actuator characterization (gains, deadband 0.88°, backlash
> 0.87°, ~75 ms latency, torque-speed): `docs/bench/README.md`.

| Item | Price | Status |
|---|---|---|
| STS3215 12V 30kg × 4 (hips) | $120 | ✅ Ordered — bus IDs 1-4 |
| STS3215 7.4V 19kg × 8 (femur + tibia) | $200 | ⚠️ Have ~6, order remaining 2 — bus IDs 5-12 |
| STS3215 7.4V 19kg × 6 (arm) | $0 | ⏸ **Phase 4 future** — carry over from SO-ARM101, IDs 13-18 reserved, not on bus for v1 |
| Feetech TTL daisy-chain cables | $20 | ✅ Ordered |
| Feetech 25T servo horns × 12 | $35 | ✅ Ordered — *horn fitment integrated into leg redesign* |
| Feetech FD debugging software (Windows) | Free | 🆕 Download — for ID setup |

**Process:** Set unique bus IDs (**1-12 active** for v1 quadruped; 13-18 reserved for Phase 4 arm) before chaining. Label each servo physically.

### Bus integrity (12 nodes @ 1Mbps over ~2 m harness)

PCB v6 includes footprints for the following bus-integrity mitigations (populate per measured bus error rate):
- **Series R** (22-100 Ω, 0603) at FE-URT-1 output — slope rate-limiting
- **Ferrite bead** at each servo entry — common-mode noise rejection
- **Star ground** at FE-URT-1 — eliminates daisy-chain ground-loop pickup

Note: Feetech bus is single-ended half-duplex TTL UART. 120 Ω differential termination (RS-485 trick) is NOT appropriate here. If bus errors persist after the above, drop baud 1M → 500k → 250k.

---

## 5. Networking (Unitree L2 + Dev Access)

| Item | Price | Status |
|---|---|---|
| Gigabit Ethernet switch (5-port) — TP-Link LS105G or NETGEAR GS305 | $15 | ✅ Owned — BENCH ONLY, not mounted on robot (L2 plugs direct into Jetson eth0; decision 2026-08-14) |
| **Cable Matters 10Gbps Snagless Cat 6 — 1ft × 1** | **$8** | ✅ Ordered — only 1 needed on-robot (L2 ↔ Jetson eth0 direct) |
| Small inductor + capacitor (LC filter on D24V22F12 output to L2) | $3 | 🆕 Order with electronics |

**Topology:**
```
L2 (192.168.1.62) ──Cat 6──→ Jetson eth0 direct (static 192.168.1.2/24)
```

Dev access on the robot is Jetson built-in WiFi. The switch stays bench gear only — a dev laptop can join via the switch on the bench when wanted.

---

## 6. Mechanical Hardware

| Item | Price | Status |
|---|---|---|
| M3/M4/M5/M6 stainless hex screw kit | $35 | ✅ Ordered |
| **leg_v6 servo screws — M2/M2.5, 6 lengths (MEASURED 2026-07-11, `docs/fastener-schedule.md`)** | **$18** | 🆕 Order — **12 active servos (4 HAA + 4 HFE + 4 KFE)** need 3 fastener families each (144 screws total, self-consistent at 12/servo): **case-mount M2 self-tap** ×40 M2×22 (HAA/KFE + HFE-near-pair) + ×8 M2×25 (HFE far pair only — femur's LA-6 underside ramp deepens that pair's floor +4.4mm, measured 6.525mm vs 2.125mm elsewhere; capped at 25 so it doesn't bottom the ~19.9mm case column); **horn M2.5** (driven side, into the ~3.05mm horn disc) ×32 M2.5×6 (HAA+KFE) + ×16 M2.5×5 (HFE — thinner LA-7 backing wall); **wheel M2.5** (idler side, into the ~2.1mm wheel disc, **no center screw** — idler boss only) ×32 M2.5×8 (HFE+KFE) + ×16 M2.5×14 (HAA — shoulder's long wheel-boss reach). M2.5×14 is an uncommon length, likely a separate order from the generic M2/M2.5 pack; add ~10% spares per length. **Confirmed too short: stock STS3215 case screws** (already known); **no verified stock length found for the horn/wheel M2.5** — source all 4 M2.5 lengths, don't assume the servo kit covers any of them (check the hardware baggie before ordering). Stock retention screw (Ø5.4×~1.5mm proud, ×1/horn = 12) ships with the servo/horn, not sourced. |
| 8x16x5mm ball bearings × 8 | $15 | ✅ Ordered — **SPARE — leg_v6 uses the servo's integral idler wheel, not external 688ZZ (vestigial from leg_v5); repurpose or ignore** |
| Standoffs, zip ties, heat shrink (assorted) | $30 | ✅ Ordered |
| **Mezzanine standoffs — 8× M3 × 20 mm M-F brass + M3 screws** | $12 | ⚠️ **CORRECTED 2026-08-18 — this said 4, and the design needs 8.** There are TWO 20 mm gaps, not one, on the same 74 × 66 pattern at (−40.5, ±33) and (33.5, ±33), stacked vertically: **4 LOWER** (floor plate z6.0 → power board z26.0, `STANDOFF_FLOOR_MM`) and **4 UPPER** (power board z27.6 → logic board z47.6, `STANDOFF_PB_LB_MM`). The old row ordered the upper set but justified it with the LOWER gap's clearances — the Ø10×17 bulk caps and the buck cards both live under the power board, not above it. The lower 20 mm is set by the caps (16 mm left them 1 mm proud); the cards are **9.02 mm** (Pololu, not the ~15 this row used to claim). ~~Total stack ≈ 41 mm < 46.9 mm trunk~~ **wrong comparison**: the real ceiling is `STACK_TOP_Z ≈ 62.22` (Teensy/Nano socket top, measured off the parsed board mesh) against a trunk plateau of 46.91 — the stack was never meant to fit inside the trunk, it runs up into the riser bay and clears the deck underside (67.9) by 5.68 mm. 📦 **RESOLVED 2026-08-18 — Aiden has a 40-piece M3 M-F set and they screw into each other.** So the requirement is not 8 single 20 mm pieces, it is **8 STACKS that each total 20 mm** (2×10, or 10+6+4, whatever the kit holds). No purchase needed. ⚠️ **But 20 mm is not a preference — each gap has a hard floor at ~18 mm, for two DIFFERENT reasons:** *lower gap* — the Ø10×17 bulk caps hang off the board's underside, so below ~18 mm they hit the floor plate (`floor_plate.scad` records the window as S ∈ [~18, 24.7]); *upper gap* — `Q1` is an 18 mm TO-220 standing on the board top, so below ~18 mm it hits the logic board underside. At the designed 20 mm the gate measures **3.00 mm** clearance under the caps and **2.00 mm** over Q1 (and only **1.40 mm** from Q1 to the logic board's own B.Cu parts) — so there is little to give away. Build each stack to 20, and put **Loctite 243** on the intermediate joints: a chain of threaded joints in a walking robot has more places to back off than a single post does. |
| **Threadlocker (Loctite 243 blue)** | **$8** | 🆕 Order |
| **Electrical tape + Kapton tape** | **$10** | 🆕 Order |
| **NYLON M3×10 screws (PA66, ~25 pk)** | **$6** | 🆕 Order — **breakaway fuses** (backlog #2): 4× L2-mast flange (deck inserts) + 4× D456 bracket row. Break ~350 N each → mount pops at ~10 N·m in a faceplant instead of the sensor/riser dying; both stay cable-tethered. HAND-TIGHT only (nylon strips), no threadlocker. Spares = the rest of the pack |
| **M3 flat washers (DIN 125, ~50 pk)** | **$4** | 🆕 Order — under EVERY head that bears on the stock trunk shell (8× shoulder-flange bolts, 4× foot bolts from below, battery-sandwich heads): spreads load into unknown-material print (load-analysis §6) |
| **M3×14 countersunk + M3 nyloc ×4** | **$3** | 🆕 Order — shoulder rev4 flange floor feet: csk head flush under the floor, nyloc + washer on the pad (drill Ø3.2 + csk the 4 floor holes at first assembly, floor_plate template) |
| **ICM-42688-P breakout (SPI/I²C)** | **$12** | 🆕 Order — **dedicated gait IMU near CoM** (backlog #14): D456/L2 IMUs are mast-mounted (high, vibey, breakaway-fused, USB/Ethernet latency) — wrong tool for the 1 kHz balance loop. Rides the existing INA226 I²C bus (0x68, 4 wires) on the mezzanine at x −3.5 ≈ CoM; permanent footprint → v7 respin |
| **Spiral cable wrap Ø6, 2 m → 3 m** | **$6** (+$1 for the extra metre) | 🆕 Order — covers the free service loops between cable clips (backlog #18, `leg_v6/cable_clip.scad`); hip + knee loops ×4 legs. **2026-07-10: qty bumped to also cover the Jetson −Y `CASE_SLOT` bundle** (DC barrel + RJ45 + USB-C, port-to-bay run, backlog #41) — same spool, no separate line needed. |
| **EVA foam 3 mm adhesive sheet + felt/kapton tape** | **$8** | 🆕 Order — battery tray floor pad (preloads the 0.8 mm slide-in slack against the shell floor, kills the 510 g rattle) + chafe strips on the shoulder-flange bottom edges over the pack (0.25 gap, integration audit #29) |
| **100 Ω 5 W resistor (precharge)** | **$2** | 🆕 Order — bridge the main switch (backlog #19): spares the switch contacts from cap-inrush arcing on every battery connect |

---

## 7. Stock NovaSM3 Sensors (v3.5 cut — most are vestigial vs new perception stack)

**Cut justification (2026-05-24):** D456 + L2 LiDAR (with their own IMUs)
replace the stock IMU + ultrasonic stack. PIR is wrong sensor class for
a mobile robot. Audio is novelty. Kept: status display + LEDs only.

### Active (v3.5)

| Item | Price | Status | Role |
|---|---|---|---|
| WS2812B RGB LEDs × 4 | $8 | ✅ Ordered | At-a-glance robot state (per `docs/notes-qol-features.md` §8) |
| SSD1331 96×64 OLED | $18 | ✅ Ordered | On-board display: battery %, IP, gait state |

### Cut from v1 — owned + on shelf

| Item | Price | Why cut |
|---|---|---|
| ~~GY-521 MPU-6050 IMU~~ | ~~$8~~ | Redundant: D456 IMU @ 200-400 Hz + L2 IMU @ 250 Hz are both higher-quality |
| ~~DFPlayer Mini Pro + 4Ω speaker~~ | ~~$20~~ | Novelty; defer to Phase 4 polish |
| ~~HC-SR04 ultrasonic × 2~~ | ~~$10~~ | D456 depth + L2 LiDAR are vastly superior obstacle perception |
| ~~MH-SR602 PIR motion sensor × 3~~ | ~~$12~~ | Wrong sensor class for mobile robot — PIR is for stationary monitors |

**Savings vs original §7: $50** (parts already owned — stay on shelf, no refund attempt)

**Arduino Nano kept** with reduced role: drives OLED (SPI) + WS2812B LEDs (1 GPIO) only. No I²C aux bus. Receives data from Jetson via USB-serial.

---

## 8. Bambu P1S Printing

| Item | Price | Status |
|---|---|---|
| PA6-CF Nylon CF × 2 spools | $170 | ✅ Ordered |
| PETG-CF × 1 spool (brick red) | $40 | ✅ Ordered |
| TPU 95A × 1 spool (yellow) | $45 | ✅ Ordered |
| PETG accent × 1 spool (white) | $30 | ✅ Ordered |
| ~~Bambu AMS HF + setup tools~~ | ~~$180~~ | ⚠️ **Owned but bypassed for v1 print workflow.** PA6-CF is hygroscopic and re-absorbs moisture in the AMS chamber within hours, defeating the 24 h pre-drying. v1 prints feed **directly from Creality SpacePi X4 → 4 mm PTFE Bowden tube → P1S extruder** so the filament stays in the heated dryer the entire print. AMS HF reserved for future PLA/PETG accent multicolor work where moisture isn't an issue. Spool retention + auto-cut bypassed; single-spool active at a time. |
| Bambu P1-series hardened steel hotend | $40 | ✅ Ordered — **mandatory** for CF-filled filaments; brass nozzle dies in <1 spool of PA6-CF |
| **Creality SpacePi X4 filament dryer + Bowden feed kit** | $170 | ✅ Ordered + active. Dual-chamber, 45-85 °C, 1-48 h timer, 4 mm PTFE Bowden outlets (top + rear). PA6-CF runs 24 h @ 70 °C pre-print then **stays in the chamber during the print** with Bowden tube routed to the P1S top-side filament input (replaces AMS feed path). |
| **Magigoo PA glue stick** | $15 | ⚠️ **Add back to order** — Bambu Lab liquid glue product page explicitly lists PLA / ABS / PETG / ASA / TPU / PET only; **not rated for PA / PA-CF / PC / PC-CF**. Per Bambu wiki PA6-CF guide, PA6-CF on textured PEI needs a PA-specific glue stick (Magigoo PA recommended) for first-layer adhesion. The "use existing Bambu glue" plan was a $15 false economy — first-layer detachment on a 10 h PA6-CF print costs more than the glue stick. Order with next batch. |

---

## 9. Wiring + Consumables

| Item | Price | Status |
|---|---|---|
| 18AWG silicone wire | $18 | ✅ Ordered |
| 22AWG hookup wire | $15 | ✅ Ordered |
| JST / Dupont connector kit | $30 | ✅ Ordered — verify crimper included |
| **M8 ring terminals, 10 AWG (×4+)** | **$5** | 🆕 Order — 5191 fuse-block stud CALIPERED **M8** (7.8 mm), 2026-07-07. Battery-in + output-out lugs on the 10 AWG feed (battery XT60 pigtail → M8 ring → 5191 stud → MRBF-30 → M8 ring → J1). Get 10 AWG barrel, M8 hole |
| **Right-angle plug adapters (−Y Jetson ports, backlog #41)** | **$8-12** | 🆕 Order — **3 ports cabled** (confirmed 2026-07-10): 1× DC barrel right-angle **5.5×2.5mm** (V12_JET power in), 1× RJ45 (ethernet) right-angle (L2 LiDAR data), 1× USB-C right-angle (D456). USB-A **dropped — not cabled** on the −Y flank. Turns each cable DOWN at the port instead of sideways off the −Y flank, so it drops straight through the riser's existing −Y `CASE_SLOT` — no cowl needed (`jetson_cowl.scad` retired in place, see `hardware/cad/chassis/jetson_cowl.scad`). Bundle sleeved in spiral wrap (§6, qty-bumped) + strain-relieved by `case_slot_grommet` below. |
| **case_slot_grommet (TPU, print ×1)** | $0 (filament only) | 🆕 Print — TPU 95A edge liner for the riser −Y `CASE_SLOT`'s cable-bearing edge (backlog #41 follow-up, replaces the retired `jetson_cowl.scad`'s protection role). `hardware/cad/chassis/case_slot_grommet.scad`, ~0.7 g. **✅ UNBLOCKED 2026-07-10 (`0f8fdb1`)**: the riser CASE_SLOT r=4 blowout is fixed + the slot widened to 9mm; the liner clips the new edge (light interference + bottom leg, zip-tie tab = primary retention). Gate clean. Print with the other TPU parts. |

---

## 10. Mechanical Decisions (Resolved)

- **L2 mounting:** top-center of chassis, on a riser ~5-10cm above the highest obstruction (arm shoulder, body panels). Centerline placement for symmetric 360° coverage and minimal yaw moment during body sway.
- **Leg redesign:** CAD complete (V5, 2026-05-26). Approach: reuse the original NovaSM3 STLs and carve an STS3215 cavity inside via OpenSCAD boolean — keeps original shape, resizes the servo pocket. 9 STLs (shoulder + coax_L/R + femur_shell_L/R + femur_cover_L/R + tibia_L/R) at `hardware/cad/leg_v5/`. Pending: first-article print (coax X-bbox tight). Rejected from-scratch attempts (V2/V3/V4) archived.
- **Servo bracket fitment:** absorbed into the leg cavity — no separate bracket. Validated on first-article leg print, not a standalone coupon.

---

## 11. Software / Accounts Checklist

Pre-hardware setup (do now):

- [ ] NVIDIA Developer account
- [ ] JetPack 6.x SD card image download
- [ ] Balena Etcher
- [ ] Feetech FD debug software (Windows or VM)
- [ ] Arduino IDE + Teensyduino
- [ ] CH340 macOS driver
- [ ] PCBWay account
- [ ] Nova Discord access
- [ ] GitHub repo for project
- [ ] Back up LeRobot Pi SD contents to Mac before reformatting

Post-Jetson-flash install list (Phase 1):

- [ ] ROS 2 Humble (Jetson native)
- [ ] librealsense2 SDK (ARM64 build)
- [ ] `ros-humble-realsense2-camera`
- [ ] Unitree unilidar_sdk2 + ROS 2 wrapper (discodyer fork)
- [ ] POINT-LIO and/or RTAB-Map
- [ ] robot_localization (EKF)
- [ ] Nav2
- [ ] micro-ROS Teensy setup
- [ ] VSCode + Remote-SSH on Mac for Jetson dev

---
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

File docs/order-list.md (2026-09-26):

# Committed Order List — Phase 0 Final Pass (v3.4)

One-shot consolidated checkout for the BOM v3.4 committed adds (~$362, ISDT 608AC charger + Pololu 4-rail redesign + full safety scope). Each item below has primary + backup vendor/SKU options. **Verify in-stock + ship-by date before clicking buy.**

> NVMe is intentionally NOT on this list — deferred until NAND prices recover (<~$100 for 1TB). See BOM §1 + open decision row 8.
> Arm-rail buck (D42V55F7) is NOT on this list — Phase 4 future. PCB v6 footprint reserved.
> v3.4 adds dedicated L2 LiDAR buck (D24V22F12, $19) after datasheet de-rating check on D42V110F12.

---

## 🆕 2026-06-14 update — order reconciliation + arm Phase-4 schematic adds

Cross-checked Amazon order history against the board BOM. **Big/long-lead items DONE since the lists above:** MRBF fuse system (Blue Sea 5191 block + Bay Marine MRBF-30 ×2), SW1 switch (Blue Sea 8282 Contura SPST), Q1 IRLB3034PBF ×5, bulk caps 1000µF/25V ×12 (FymuSing — Ø10×17mm; fits Ø12.5 land + 5mm pitch, clears the 20mm standoff gap, 1mm over the 16mm low-profile spec → fine), 12AWG silicone wire, 5/16" ring lugs, M3×20 mezzanine standoffs, full bench kit (30V/10A PSU, IR thermometer, 24MHz logic analyzer, LCR/transistor tester, 100W load resistors, solder wick).

Arm Phase-4 now wired into the power board (schematic only, ERC clean, F8+route+gerber pending): U5.EN re-gated VBAT_PROTECTED→EN_BUCKS · **J14** arm output XT30 added (was a dangling net) · **U12** arm INA226 added (addr **0x45**, DNP). See [[project-power-board-arm-phase4]].

---

## 🟢 FINAL pre-build order (both boards + Phase-4) — 2026-06-15

Full multi-phase, both-board audit. Both boards are routed + DRC-clean (logic: 0 unconnected / 0 errors; power: clean, and the J14/EN/U12 edits add **zero** new orderable parts). Teensy 4.1 ✅ owned, Nano ✅ ordered, no DNP surprises → **BOM is frozen.** This is intended to be the **last DigiKey/Mouser order**. The 3 non-DigiKey lines at the bottom are separate-vendor orders that can't go on DigiKey.

### A. DigiKey / Mouser cart — ONE order

**Active / ICs**
- LM393DR SOIC-8 ×2 (power U8 + spare)
- BSS138 SOT-23 ×5 (power Q2/Q3/Q4 + spares)
- 74**LVC**125 SOIC-14 ×5 (logic U7 — board uses LVC, 5V-tolerant; keep it) — *Q1 IRLB3034 ✅ already ordered*

**Electrolytics** — radial Ø10 5mm-pitch (2026-06-16 board review split by rail voltage):
- **C6 (V12_L2, 12V): 470µF/25V** (2.1× ✓) — Nichicon UPW1E471MPD
- **C8 + C9 (VBAT_PROTECTED = raw 16.8V 4S rail): 470µF/25V** — Nichicon UPW1E471MPD. ⚠️ **REVERTED from 35V (2026-06-17 PCB review):** 35V part (UPW1V471MPD) is ~Ø10×**20mm** tall and C8/C9 sit *under the logic board* in a ~20mm mezzanine gap → it would hit the top board. **25V is correct anyway** — 16.8V/25V = 67% util, within the 80% derating rule (25×0.8=20V > 16.8V); 25V Ø10×16mm fits the stack (4mm clear). Do NOT use the 35V part here (height).
- buy ~5 (3 board + spares). *1000µF C1–C5 ✅ ordered (V7V5_LEG/V12_HIP). ⚠️ Those 25V leg caps need the **TVS clamps populated** — e-stop regen can drive V7V5_LEG to ~21V (1.19× on 25V) until the SMBJ8.5A clamps it.*

**Inductor**
- 22µH ≥2A power inductor ×1 (Bourns SRR1260-220M) — power L1 / L2-LiDAR LC filter

**0603 passives — consolidated across BOTH boards** (buy 10-packs, Yageo RC0603 1% / X7R)
| Value | Qty | Refs |
|---|---|---|
| 10k | 9 | pwr R5/R7/R8/R9/R13 + logic R7×2 |
| 1k | 5 | logic R2–R6 |
| 100k | 2 | pwr R2/R16 |
| 4.7k | 2 | pwr R11/R12 |
| 22k · 470k · 1M | 1 each | pwr R3/R14/R15 |
| **11.3k 1%** · **12.1k 1%** | 1 each (buy a few — trip-point) | pwr R4/R6 |
| 22R | 2 | logic R1 (bus series) |
| 100nF (C0603 X7R) | 4 | pwr C7 + logic C1 |
| 600R ferrite (L0603) | 2 | logic FB1 |

**Connectors**
- JST **B3B-XH-A** ×4 (power J8 + logic J11 + spares) — DK 455-2247-ND
- 🔴 **IDC box header 2×06 2.54 shrouded ×2** (J20 on *each* board) + **12-way ribbon** + 2 IDC receptacle ends (mezzanine link — currently have zero; pair required, two males can't mate)
- 2.54 pin-header breakaway strip ×1 (Sullins PRPC040SAAN) — covers pwr J2/M1 + logic J10/J21/J9/JP1
- 2.54 shorting jumpers ×3 (JP_BUS_MASTER, logic JP1)
- ✅ **SW1 screw block → TB007-508-02BE — ORDERED ×10 (2026-06-22)** (DK 102-6203-ND, 16A UL / 18A IEC, 5.08mm, **14mm tall — fits 20mm gap**, fits TB132; replaces OOS MKDS). 1 for SW1 + spares; SW2 = existing kit block. Matches the ~18A Contura switch. Drill 1.2→1.5mm tweak queued for Q1 pass.

**TVS (off-board, power rails incl. Phase-4 arm)**
- SMBJ8.5A ×5 (2 leg + 1 arm Phase-4 + spares) · SMBJ13A ×5 (hip + L2 + spares) — cathode band to +, across injection XT30 pigtails

### B. NOT DigiKey — separate-vendor orders (don't forget)
- **Pololu:** D42V55F7 arm buck (~$32) — Phase-4 install
- **Amazon:** +1 INA226 20A R002 module — arm U12 consumed the 4th/spare → 0 spares now
- **Feetech / AliExpress:** 6× servo daisy-chain cables — Phase-4 arm (user handling)
- ~~**PCBWay:** both boards ×5 + stencils — **after** power-board routing (J14/EN/U12) + gerber regen~~ → **done at JLCPCB 2026-07-01**, see STATUS.md (no stencils — hand-soldered by design)

### Why this is the last DigiKey trip
Both boards DRC-clean → no design churn pulling new parts; pending power edits add nothing orderable; Phase-4 electronics folded in (TVS arm clamp in the ×5). Only re-order risk = a 1% trip-point value (R4 11.3k / R6 12.1k) failing bench trim → buy a couple neighboring values as insurance.

---

## 🆕 2026-06-18 — cart audit (actual DigiKey cart vs the FINAL list above)

Audited the in-progress DigiKey cart against §A. **Cart deviates — fix before checkout:**

🔴 **Wrong part in cart:** had **SN74HC125D** (DK 296-1192-5-ND) — plain HC, **NOT 5V-tolerant**. Servo bus is 5V-TTL into a 3.3V-powered buffer → HC inputs over-driven. Replace with **SN74LVC125AD, DK 296-8453-5-ND** (74LVC, supply 1.65–3.6V, SOIC-14, 5V-tolerant inputs). Qty 5–10. *(Verified against datasheet 2026-06-18.)*

🟢 **Prior DigiKey order ($25.85, ×10 each) CONFIRMED covers:** LM393DR · BSS138 · 470µF/25V (UPW1E471MPD) · 100nF (CC0603) · **BHR-12-VUA J20 box headers** · SRR1260-220M (L1) · PRPC040 strip · full power-board 0603 R-set (10k/100k/4.7k/22k/470k/1M + **11.3k & 12.1k 1% trips**) · JST B3B-XH-A.

✅ **ORDERED 2026-06-22:** SMBJ8.5A/SMBJ13A TVS · Teensy/Nano sockets (PPTC241/151) · J20 ribbon (IDSD-06-D-09.00).

⚠️ **Stock resolution (2026-06-22):**
- **1kΩ + 22Ω 0603 — Yageo originals BACK IN STOCK** (311-1.00KHRCT-ND / 311-22.0HRCT-ND, immediate, ~$0.025 ea) → **use originals** (orig spec, cheaper). Vishay CRCW06031K00FKEAC (541-3949-1-ND) / CRCW060322R0FKEA (541-22.0HCT-ND) kept as **documented drop-in fallback** if Yageo lapses again.
- **SW1 block — MKDS 277-1263 still OOS (17-wk)** → substitute **TB007-508-02BE — ✅ ORDERED ×10 (2026-06-22)** (102-6203-ND, $0.53 ea). 16A UL / **18A IEC**, 5.08mm, **body 14mm tall → clears 20mm mezzanine gap (edge-mounted, screw/wire in open air)**, fits TB132 — **needs SW1 drill 1.2→1.5mm tweak (Q1 board pass)**. Matches ~18A Contura switch; NOT a 30A swap (fuse is kA-short protection, switch caps path at ~18A). 1 for SW1 + 9 spares (can populate SW1 on multiple ×5 fab boards).

✅ **ORDERED 2026-06-22 — logic-board parts (were in NEITHER prior order; DK# verified 2026-06-18):**
| Part | DK # | Mfr P/N | Qty | Ref |
|---|---|---|---|---|
| SN74LVC125AD (SOIC-14) | 296-8453-5-ND | SN74LVC125AD | 5 | U7 (HC→LVC swap) |
| 1kΩ 0603 1% | 311-1.00KHRCT-ND | RC0603FR-071KL | 10 | logic R2–R6 (OLED SPI) — back in stock; fallback 541-3949-1-ND |
| 22Ω 0603 1% | 311-22.0HRCT-ND | RC0603FR-0722RL | 10 | logic R1 (bus series) — back in stock; fallback 541-22.0HCT-ND |
| 600Ω@100MHz ferrite 0603 | 490-5258-1-ND | BLM18KG601SN1D | 10 | logic FB1 (bus integrity) |
| 2.54 shorting jumper | S9001-ND | SPC02SYAN | 10 | JP_BUS_MASTER + JP1 |

✅ **Confirmed NOT ordered (2026-06-22): SN74HC125D (296-1192-5-ND)** — wrong logic family; the LVC (296-8453-5-ND) is the correct part.

🟠 **Q1 gate-harden parts — C_gs + D1 zener ✅ ORDERED 2026-06-22 (board edit still pending):**
| Part | DK # | Mfr P/N | Qty | Ref |
|---|---|---|---|---|
| 10kΩ 0603 1% | 311-10.0KHRCT-ND | RC0603FR-0710KL | ✅ prior order | R17 (gate series / soft-start) |
| **0.47µF 0603 X7R 25V** | **1276-2082-1-ND** ✅verified | CL10B474KA8NFNC (Samsung) | 10 ✅ordered | **C_gs (soft-start cap) — NEW.** "474"=470nF (NOT "470"=47pF) |
| 18V zener **SOD-123F** | **4878-BZT52C18CT-ND** ✅verified | BZT52C18 (Diotec) | 10 ✅ordered | D1 (gate-source clamp, backstop). 500mW, Zzt 45Ω. **Use SOD-123F footprint** (larger than SOD-123). |
| 100kΩ 0603 1% | 311-100KHRCT-ND | RC0603FR-07100KL | ✅ prior order | R_gs (gate bleed, optional) |

**Q1 protection — ⚠️ MARGINAL, treat as backstop (2026-06-18, revised after deeper analysis):**
Q1 (IRLB3034) gate = VBAT_PROTECTED, **drain = BATT_NEG (tab/pin2, battery−), source = GND (pin3)** →
Vgs = gate−source ≈ full pack (≤16.8V), Vgs(max) = **20V** → only **3.2V headroom**. Hot-plug LC ring
on VBAT (≈5470µF + lead L, no on-board TVS) can ring to ~22–33V → Vgs > 20V → gate-oxide kill. ⚠ superseded by docs/power-chain-fmea.md#pc-10 (hot-plug sees C8+C9 = 940 µF; C1–C6 are on buck outputs)

> **⚠️ Terminal correction (2026-06-27):** earlier text said "source = BATT_NEG" — WRONG. For IRLB3034
> (G-D-S = pin 1/2/3) the board has **drain = BATT_NEG, source = GND** = the correct low-side reverse-prot
> orientation (body diode anode=GND/source, cathode=BATT_NEG/drain → blocks a reversed pack). ✅ Board correct.
> ~~The gate-harden (C_gs/D1/R_gs) ties to **BATT_NEG = drain**, not the literal source — still works: BATT_NEG ≈ GND
> (≤21mV steady, ≤0.7V during pre-turn-on body-diode conduction) and clamping gate-to-drain bounds Vgs
> *conservatively* (Vgd ≥ Vgs → zener trips protecting Vgs ≤ Vz). "gate-source" below = gate-to-BATT_NEG in practice.~~
> **→ corrected 2026-09-25, #429: this argument checked NORMAL polarity only, and it breaks the reverse
> protection.** With the pack reversed, `BATT_NEG` is the POSITIVE terminal. `D1` (anode on `BATT_NEG`) then
> conducts forward into the gate and lifts it above the source (GND), so Q1 turns ON and passes the reversed
> pack. That is the one case Q1 exists for. (FMEA row: `docs/power-chain-fmea.md#pc-01`.) Board file confirms `D1`.2, `R_gs1`.2 and `C_gs1`.2 all on
> `BATT_NEG` (`Q1`.2). The network must reference the source, `Q1`.3. Rework and the reversed-`J1` bench test:
> `hardware/pcb-mods/BUILD_PLAN.md` §6 gate 9a. Symbol root cause and v7 fix: BUILD_PLAN §8.

**PRIMARY fix = gate soft-start on Q1 (prevents the ring at the source):** Q1 is already the pass
element in the path. Add **C_gs (gate-source cap)** so the gate ramps slowly through R17 → Q1 turns
on gradually → bulk caps charge gently → **no abrupt step, no LC ring, no overshoot.** Same R17 does
double duty (soft-start + zener clamp current-limit).
- **R17 = 10kΩ** (NOT 100Ω/1k). Bigger = tighter zener clamp AND slower ramp. Clamp = Vz + Iz·Zz
  (Zz≈25Ω): 33V spike → Iz=(33−18)/10k=1.5mA → clamp ≈ **18.04V < 20V ✓**. Gate quiescent drop
  negligible (gate leakage only). (100Ω→~21V fail; 1k→18.4V ok; 10k→18.04V best.)
- **C_gs = 470nF.** τ = R17·C_gs = 10k·470n = **4.7ms**. LC ring period = 2π√(LC) ≈ 2π√(1µH·5470µF)
  ≈ **0.5ms**. Charge ramp (~3–5×... effectively spreads inrush over ~5–15ms) **≫ 0.5ms → overdamped,
  no ring.** C_gs (470nF) ≫ Ciss (~3nF) so it dominates the ramp.
- **D1 18V zener = backstop** for any residual transient. Tight (Vz 16.8–19.1V, low corner = full
  pack) but with soft-start preventing the ring it's rarely exercised.
- **R_gs 100k (optional)** gate-source bleed → defined gate + discharges C_gs on disconnect (clean
  turn-off). Q1 turn-off isn't safety-critical (reverse-prot; off when no battery) but good practice.
- **⚠️ SOA CHECK (gating):** during soft-start Q1 is in linear region dissipating the charge energy
  **½CV² = ½·5470µF·16.8² ≈ 0.77 J** over the ~5–15ms ramp. Must stay inside IRLB3034's SOA (check
  the 10ms single-pulse line). If marginal → use a **precharge resistor** (energy in R, not the FET)
  instead, or slow/speed the ramp. **This sets whether soft-start-on-Q1 is safe vs needs precharge.**
- **Cleaner alt if SOA fails:** precharge resistor (bypassed after), or gate divider (Vgs→~12V) +
  smaller zener, or a ±25V-Vgs FET.
- **BENCH-VALIDATE** the real VBAT transient on the scope (Phase-5) before trusting any of it. Do NOT
  fab assuming the gate is solved.

✅ **Received since (Amazon):** M3×20 standoffs, MRBF-30 + Blue Sea 5191, 12AWG wire, ring lugs, solder wick, bench gear (PSU / logic analyzer / 1Ω loads).

**Mounting-hole isolation:** the **7mm copper keepout** (all 4 holes, all layers) is the fix — with it, the owned **brass M3×20 ×50 (PATIKIL)** are safe on all 4 (no copper under flange/barrel). Nylon at H1 = optional extra, NOT required to order.

**Verify owned before fab:** XT30 ≥18 mating pairs · real 6000mAh pack physical dims (re-measure → `dimensions.md §5` + LiPo pocket, currently flagged).

---

## 1. Power conversion + charging

### ISDT 608AC LiPo charger — ~$60 ✅ ORDERED
- Modes needed: balance charge, **storage**, discharge
- On arrival: power up no-battery, verify storage-mode menu works, set LVC alarm to 3.3V/cell = 13.2V

### LiPo safe bag — ~$15 ✅ ORDERED
- Fireproof fiberglass bag sized for 4S 6000mAh packs (verify owned bag fits the larger pack)

### XT60 jumper (for 608AC battery input) — $0 ✅ SUPPLIED WITH OVONIC KIT
- Confirmed in Ovonic 4S LiPo kit. Skip purchase.

### XT60 charging lead — $0 ✅ SUPPLIED WITH OVONIC KIT
- Confirmed in Ovonic kit (XT60 ↔ JST-XH balance, 5-pin for 4S). Skip purchase.

### Pololu D42V55F12 (Jetson 12V rail) — ~$32
- **Primary:** `pololu.com` direct — find on D42V55Fx family page (Pololu's search may not return the F12 SKU; navigate the family page and pick 12V from the variant dropdown)
- **Backup:** DigiKey / Mouser (same part #)
- **Why:** 12V fixed out, 12-60V in, 4.5A typ @ 42V Vin (derates to ~3A at 14.8V Vin per Pololu's de-rating graph). Reverse-polarity protected.
- **LVC reminder:** min Vin is 12V, so set LiPo low-voltage alarm at **3.3V/cell = 13.2V**.
- **Bench validation:** sweep Vin 16.8V → 13.2V under Jetson MAXN load (≈25W). 12V rail should stay flat (no >100 mV droop).

### Pololu D42V110F7 (leg 7.5V rail, 8× STS3215 19kg) — ~$60
- **Primary:** `pololu.com` direct, item #5674
- **Why:** 7.5V fixed out (within STS3215 6-8.4V spec), 7.6-60V Vin range, 10A typ @ 42V Vin (derates at our 14.8V Vin per Pololu's de-rating graph). Sized for walking-gait avg 5-8A with bulk caps absorbing 25-40A impact transients near point of load.
- **Bench validation:** load with 1×, 4×, then 8× STS3215 19kg in a walking-gait stand-in (alternating PWM @ 2 Hz). Watch thermal rise, voltage sag, and transient overshoot. Add bulk caps (1000 µF) at each star injection point if observed.

### Pololu D42V110F12 (hip 12V rail, 4× hip STS3215 30kg only) — ~$60
- **Primary:** `pololu.com` direct, item #5677
- **Why:** 12V fixed out, 12-60V Vin range, 9A typ @ 42V Vin (derates lower at 14.8V Vin). Sized for 4× hip STS3215 30kg sustained ~8A. **L2 LiDAR moved off this rail** to a dedicated buck (v3.4) — combined hip+L2 load was margin-thin under de-rating.
- ⚠️ **TIGHTEST rail (2026-06-16 review):** ~8A load vs ~9A derated ≈ **1.1× margin** — the thinnest of all bucks. The bench thermal-IR step below is mandatory, not optional; have the D24V150F12 upgrade path ready if it runs hot.
- **Bench validation:** load with 1× then 4× 30kg hip walking-stand-in. Thermal IR after 10 min sustained. Confirm derated continuous capacity matches your measured load. If sustained pull >7A and thermal is concerning, plan parallel modules or upgrade to D24V150F12.

### Pololu D24V22F12 (L2 LiDAR 12V dedicated rail, v3.4 split) — ~$19
- **Primary:** `pololu.com` direct — find on D24V22Fx family page (`pololu.com/category/107/d24v22fx-step-down-voltage-regulators`), pick 12V variant
- **Why:** 12V fixed out, ~2.2-2.6A max, 36V Vin max, 85-95% efficiency. L2 LiDAR draws ~1A → 2.6× headroom. Dedicated buck = clean power for the LiDAR, no servo transient ringing on its supply.
- **Bench validation:** load with L2 LiDAR active. Scope output for ripple at buck switching frequency (~400 kHz) before/after LC filter.

---

## 2. Networking

### Gigabit Ethernet switch (5-port) — ~$15 ✅ ORDERED
- TP-Link LS105G or NETGEAR GS305 (5-port unmanaged gigabit)
- **NOT on the robot (2026-08-14)** — L2 plugs direct into Jetson eth0, point-to-point. Switch kept as bench gear only, for a dev laptop to join the LAN on the bench.

### Cable Matters 10Gbps Snagless Cat 6 — 1ft, ×2 minimum (×3 with spare) — ~$8 ✅ ORDERED
- 30cm length, snagless boot, Cat 6 (gold-flashed per TIA/EIA-568 spec by default), 10 Gbps rated headroom
- Wiring on-robot: L2 ↔ Jetson `enP8p1s0` direct, 1 cable. Remaining cables spare / bench-switch use.

### LC filter parts for L2 12V tap — ~$3
- 1× inductor: ~22 µH, ≥2A rated (DigiKey series-resonant choke)
- 1× electrolytic cap: 470 µF, 25V
- Bundle into the next DigiKey / Mouser order to save shipping

### 🔴 MRBF-30 fuse + 5191 block (was: Class T) — ~$40 (CRITICAL GAP found 2026-06-12 state-matrix review)
Spec'd in PCB README §1 since the beginning, F1 deliberately moved OFF-BOARD 2026-06-04
(LiPo dead-short = 10–20 kA; only Class T's 20 kA AIC interrupts it — see research notes
2026-05-17 §9) — **but it never entered this order list.** Right now the battery lead is
unfused: a chafed wire or dropped tool across VBAT is the one fire-class failure on the robot.
- ✅ **CHOSEN 2026-06-12: MRBF instead of Class T** — Blue Sea **5191 Surface Mount** block
  ($24) + **Bussmann MRBF-30** fuse (~$10). Engineering note: the 2026-05-17 Class T rationale
  assumed 10–20 kA short current (large-bank figure); this 4S **6 Ah pack (Ovonic ×2, used one at a
  time — NOT paralleled)** real Isc = 16.8 V ÷ ~4–10 mΩ ≈ **1.7–4 kA**, vs MRBF's 10 kA AIC (≈9 kA at 16.8 V) → 2–5× margin, at
  ⅓ the size/weight of a Class T block — better fit for the chassis. Class T (5007 + JJN-30)
  remains the upgrade path if the pack ever grows or parallels.
- Install: 5191 screwed to chassis near the pack; battery XT60 pigtail → 12 AWG (12-10) ring → stud →
  MRBF-30 → output ring → J1 lead.
- Still banned: ANL/MIDI/blade (1–6 kA AIC — can fail-to-interrupt even on this pack).

### 🟡 LiPo balance-lead buzzer alarm — ~$5 (gap found 2026-06-12)
If the UBEC/V5_AUX dies mid-run, BOTH LM393 LVC stages go silently dead (R16 defaults rails
ON) and the Teensy dies with it — frozen robot drains the pack with no electronic protection.
Independent last line: balance-plug buzzer alarm set to **3.3 V/cell**, plugged in whenever
SW1 is on. ✅ OWNED (verified 2026-06-12): FLY RC 5-pack purchased 2026-05-16, pre-set 3.3 V.
Operational rule: buzzer rides the balance plug any time the robot is switched on.
- ✅ UBEC module VERIFIED OWNED (2026-06-12): SoloGood 5V/5A UBEC ×2, purchased 2026-05-03
  (input 5.5–35 V covers 4S; second unit = shelf spare). Listing re-confirmed 2026-08-08.
  ⚠️ **"5 A ≈ 10× the V5_AUX load" was WRONG — it is 3.3×.** `power-budget.md` Rail 5 totals
  **1.5 A continuous** (switch 0.6 + fans 0.5 + OLED/WS2812B 0.3) and says "3× headroom".
  Still ample, but 30% rail utilisation is not 10%, and the inflated figure is exactly what
  would later justify hanging another load on this rail.
  ⚠️ Also note these hobby UBECs are commonly rated **5 A peak / ~3 A continuous**; the
  datasheet claim is not split. Against 1.5 A that is still fine — but the headroom is
  ~2× on the conservative reading, not 3.3×.

  **Wiring to `J2` (4 wires into a 3-pin header — documented nowhere until now):**

  | UBEC wire | goes to |
  |---|---|
  | input **red** | `J2`.1 `VBAT_PROTECTED` |
  | input **black** | `J2`.2 `GND` |
  | output **red** (servo plug) | `J2`.3 `V5_AUX` |
  | output **black** (servo plug) | `J2`.2 — **same pin, commoned** |

  The module has separate input and output grounds; the board has one GND pin. **Splice the
  two blacks into a single pigtail before the header** — the input lead is ~20 AWG and will
  not share a 1 mm hole with the servo lead.
  Buzzer still required — the spare doesn't help mid-run.
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

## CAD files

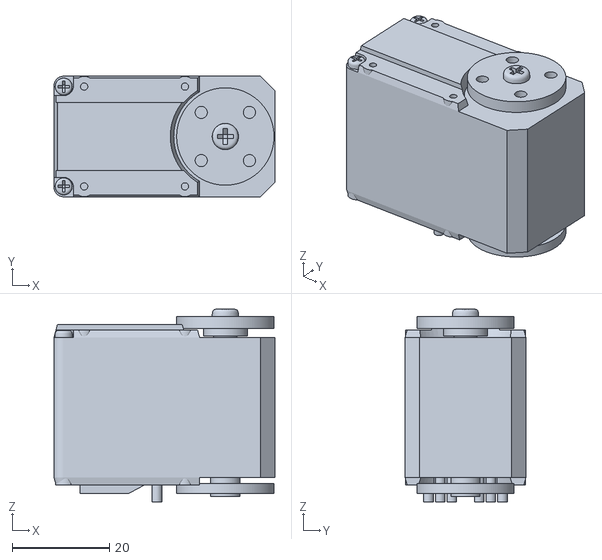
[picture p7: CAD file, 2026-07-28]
hardware/cad/assets/servo.stl
45.4 x 24.8 x 39.6

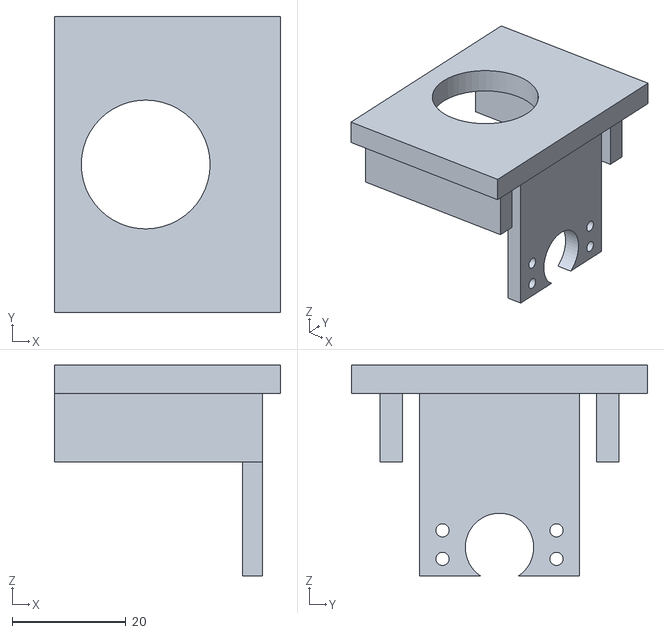
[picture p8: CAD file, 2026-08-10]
hardware/cad/chassis/control_pod.stl
39.6 x 52.0 x 37.0

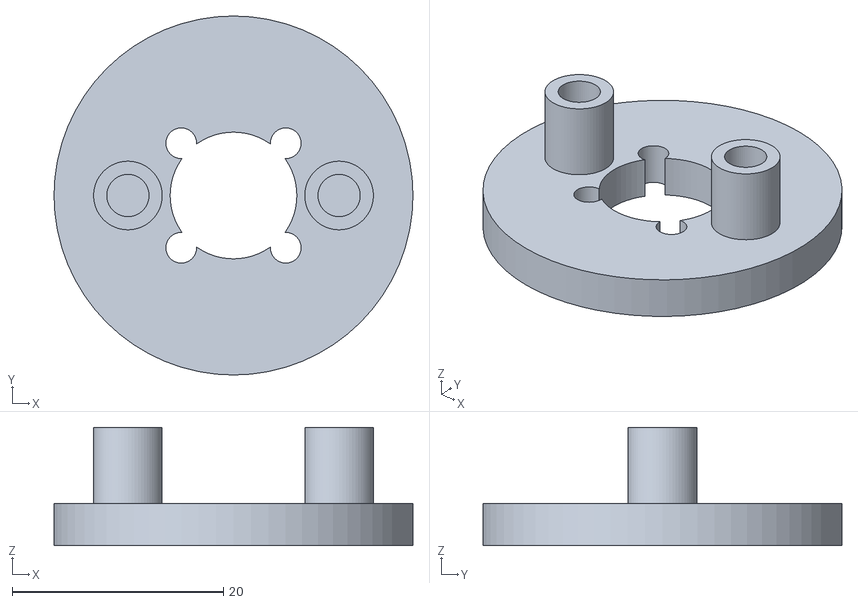
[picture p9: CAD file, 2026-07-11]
hardware/cad/demo/demo_horn_bracket.stl
34.0 x 34.0 x 11.2

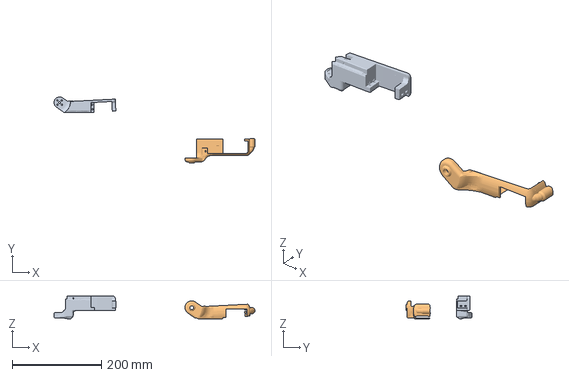
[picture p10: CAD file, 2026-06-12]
hardware/cad/femur_L_and_Cover.3mf
450.0 x 148.0 x 51.1 mm
femur_L.stl
femur_cover_L.stl

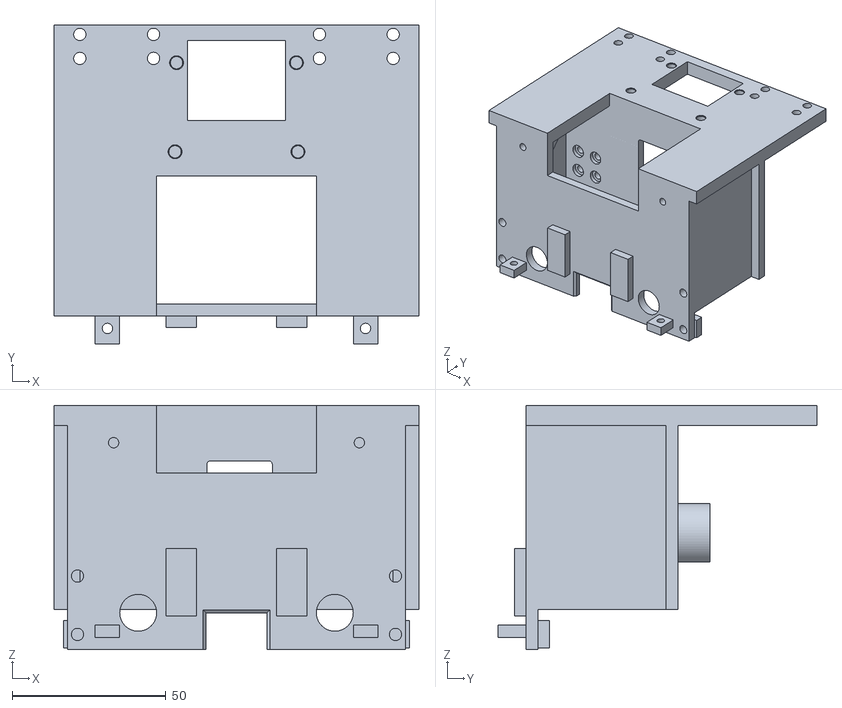
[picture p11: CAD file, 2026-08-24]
hardware/cad/leg_v6/shoulder_sw1.stl
118.8 x 103.7 x 79.5

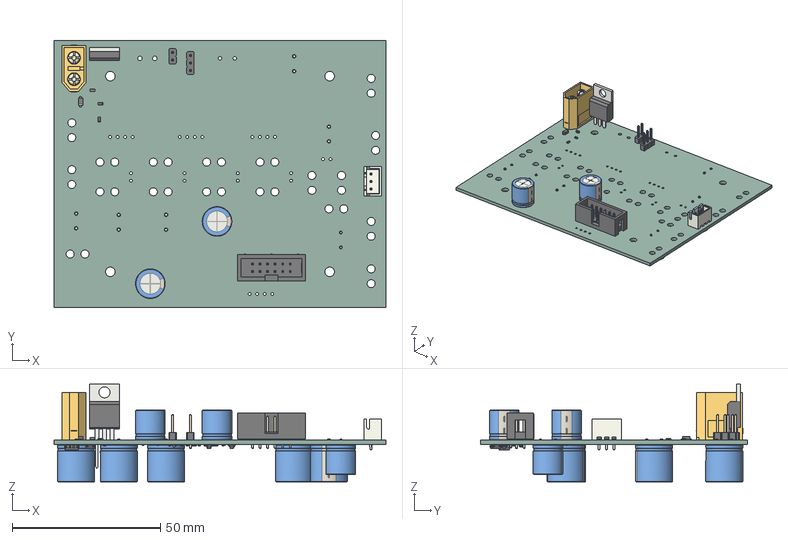
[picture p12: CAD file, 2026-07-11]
hardware/pcb-mods/nova_pcb_v6_power_v2/nova_power_v2.step
112.0 x 90.0 x 33.0 mm
D_SOD-123F
IDC-Header_2x06_P2.54mm_Vertical
R_0603_1608Metric x 16
C_0603_1608Metric x 2
PinHeader_1x02_P2.54mm_Vertical
AMASS_XT60-M_1x02_P7.2mm_Vertical
CP_Radial_D10.0mm_P5.00mm x 3
JST_XH_B3B-XH-A_1x03_P2.50mm_Vertical
PinHeader_1x03_P2.54mm_Vertical
TO-220-3_Vertical
CP_Radial_D12.5mm_P5.00mm x 5
SOT-23 x 3
SOIC-8_3.9x4.9mm_P1.27mm
nova_pcb_v6_power_v2_PCB

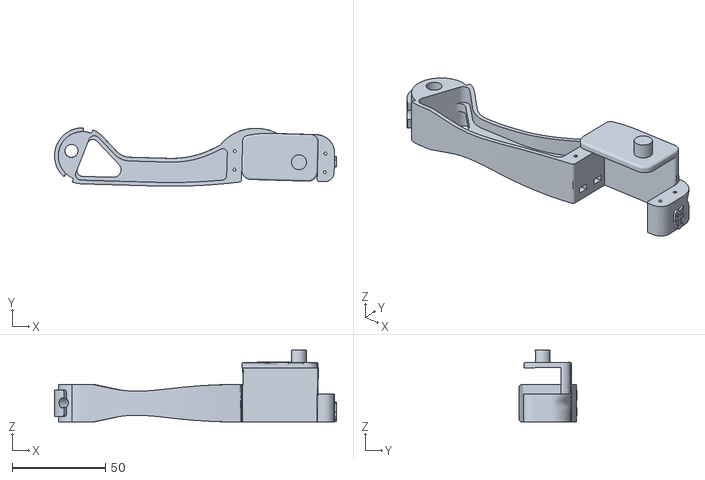
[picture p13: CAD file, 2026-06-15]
ros2_ws/src/nova_description/meshes/SM3_Frame_RightTibia.stl
151.0 x 31.3 x 38.5

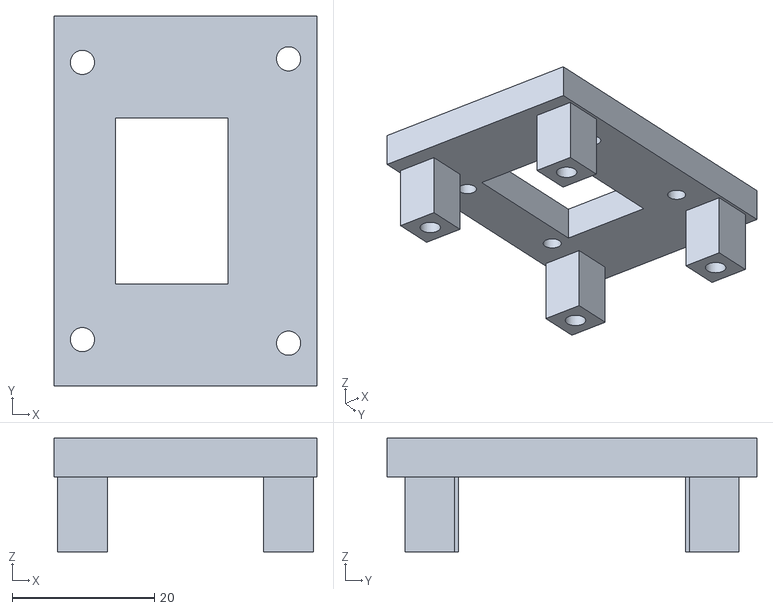
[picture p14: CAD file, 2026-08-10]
hardware/cad/chassis/oled_tray.stl
37.0 x 52.0 x 16.0

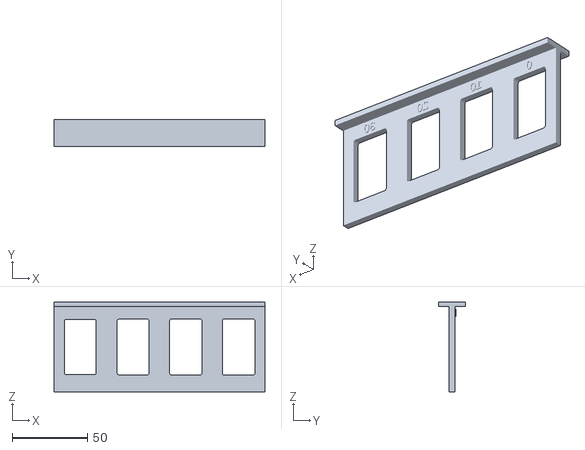
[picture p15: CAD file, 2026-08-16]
hardware/cad/leg_v6/sw1_coupon.stl
140.3 x 18.0 x 59.8

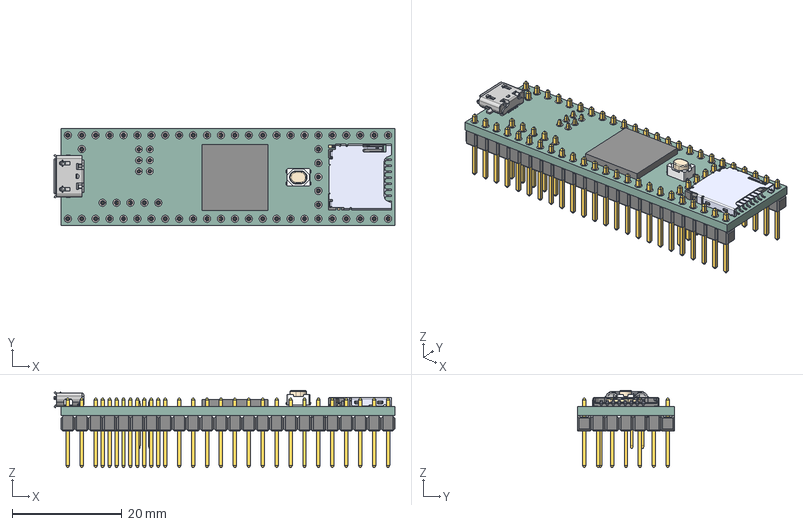
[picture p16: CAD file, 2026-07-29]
hardware/pcb-mods/3dmodels/Teensy_4.1_Headers.step
62.2 x 17.8 x 14.1 mm
114-00841-68--3DModel-STEP-56544
MIMXRT1052CVJ5B
MicroUSB Molex 473460001
Pin Header 1x6 TH Pitch 2.54mm x 4
Pin Header 1x6 TH Pitch 2.54mm v1(Mirror) x 4
Pin Header 1x5 TH Pitch 2.54mm x 2
Pin Header 1x1 TH Pitch 2.54mm
pin header 1x3 pitch 2mm heigth 5mm x 2
PTS810 SJK 250 SMTR LFS

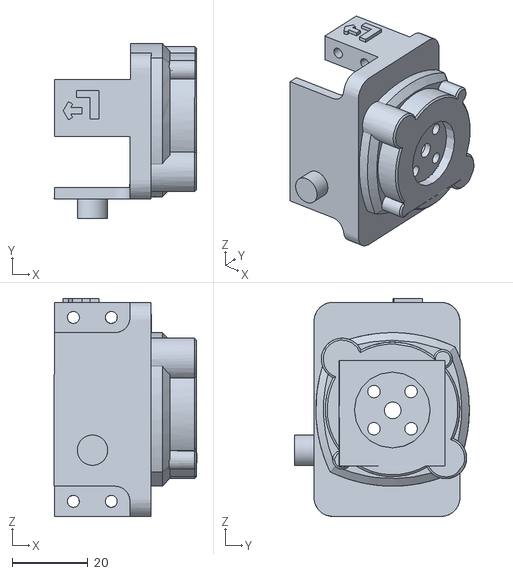
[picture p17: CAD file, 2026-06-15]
ros2_ws/src/nova_description/meshes/SM3_Frame_LeftCoax.stl
37.6 x 46.1 x 57.5

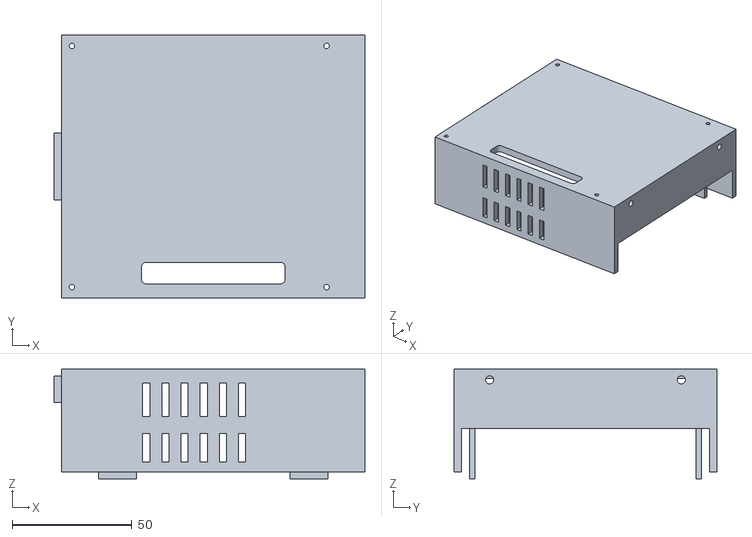
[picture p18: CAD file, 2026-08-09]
hardware/cad/chassis/riser_bay.stl
129.8 x 110.0 x 45.9

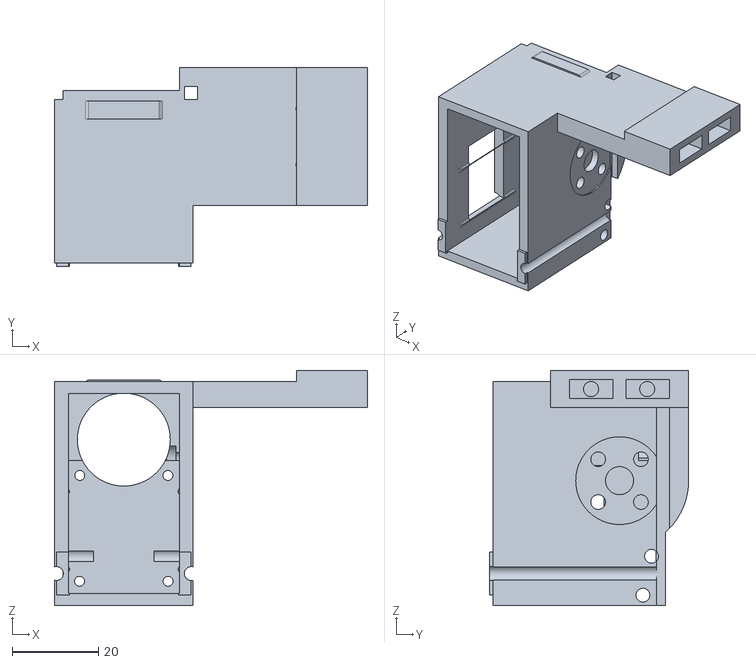
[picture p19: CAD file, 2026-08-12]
hardware/cad/leg_v6/coax_R.stl
72.4 x 46.2 x 54.4

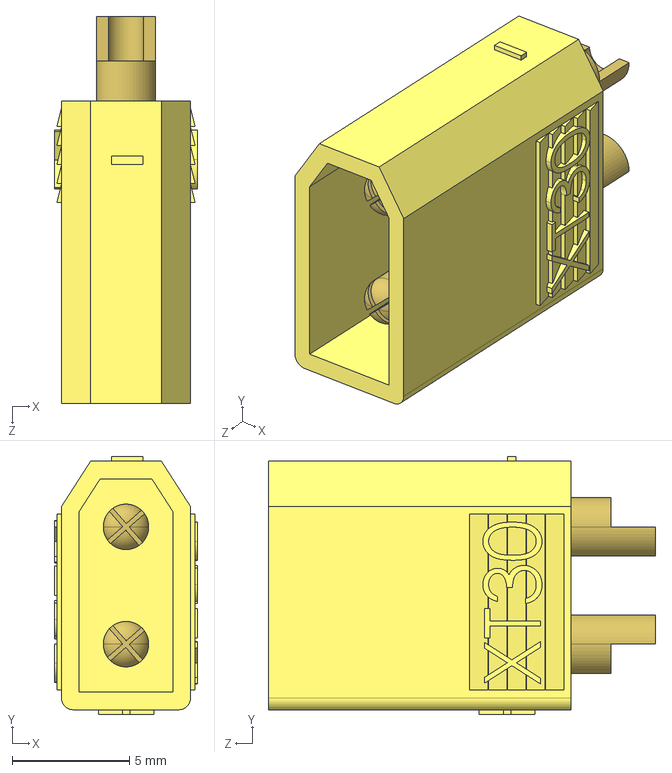
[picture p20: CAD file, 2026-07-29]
hardware/pcb-mods/3dmodels/XT30-M.step
6.10 x 11.0 x 16.5 mm

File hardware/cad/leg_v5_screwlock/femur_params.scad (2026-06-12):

// Femur cavity placement — shared by shell + cover scripts so holes match.
// Copied verbatim from leg_v5/femur_params.scad (paths are absolute).
// 2026-06-07: synced with leg_v5 — servo shifted toward coax (active-horn side),
// R rotation corrected to a true mirror (−90, was +90). See leg_v5/femur_params.
FEMUR_CAVITY_CENTER_R = [37, 24, 10];
FEMUR_CAVITY_ROT_R    = [-90, 0, 0];
FEMUR_CAVITY_CENTER_L = [37, -24, 10];
FEMUR_CAVITY_ROT_L    = [90, 0, 0];

FEMUR_SHELL_L = "/Users/afox/codebases/NOVA/original_body_files/SM3_Frame_LeftFemur.stl";
FEMUR_SHELL_R = "/Users/afox/codebases/NOVA/original_body_files/SM3_Frame_RightFemur.stl";
FEMUR_COVER_L = "/Users/afox/codebases/NOVA/original_body_files/Covers/SM3_Cover_LeftFemur.stl";
FEMUR_COVER_R = "/Users/afox/codebases/NOVA/original_body_files/Covers/SM3_Cover_RightFemur.stl";

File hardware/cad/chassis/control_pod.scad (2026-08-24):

// =============================================================================
// CONTROL POD — E-stop (slap-down) + SSD1331 OLED, rear-top of the robot
// =============================================================================
// The tray HOOD is retired (official Jetson case adopted), which orphaned the
// E-stop pod + OLED. This part re-homes them at the REAR-TOP, in the pocket
// BEHIND the riser rear wall (x < -63.35).
//
// The rear is CONGESTED (all mapped by the free-space probe 2026-07-08):
//   * the two REAR SHOULDERS occupy x-63.5, |y|>14, z45..72 — structure at the
//     wall must stay in the CENTRAL y±14 channel;
//   * the mezzanine STACK sits 0.65 mm behind the 3.2 mm riser wall (x>-59.5),
//     so no INNER heat-set boss fits — the riser instead grows OUTER bosses that
//     protrude into the (clear) central pocket, and the pod bolts to their rear
//     faces (x-66.5). riser_bay POD_MOUNT + the guard exception cover this;
//   * the stock TRUNK rear lip fills the low centre (x≈-67, y±5, z40..58);
//   * the rear SHOULDER tops end at z≈80 -> above that the rear is OPEN.
// So: a CENTRAL COLUMN bolts to the riser pocket-bosses (y±10, z61/66); the deck
// cantilevers back over the pocket; the E-stop block hangs at x-87 (front x-71
// clears the boss/trunk lip, rear x-103 clears the shoulder at x-104); the OLED
// rises above the shoulder line (z>80) where it's clear.
//
// Frame = TRUNK frame (+x FRONT, z up).
// E-STOP (mxuteuk 22mm 2NC, HB2-ES544, VERIFIED specs 2026-07-08: Ø22 hole,
//   Ø40 mushroom, 77 total length, panel max 6mm): UP on the deck (z90, 5mm <
//   6mm max OK). The ~30×30 × ~48-deep contact block hangs into the pocket
//   (gussets flank it at y±17); Ø22 barrel through the Ø22.6 hole + supplied nut.
// OLED: SPLIT OFF (#40), then MOVED OFF this part entirely (#35, 2026-08-10).
// It was a separate bracket (oled_mount.scad) bolting
//   to the pod deck's +y edge (2x M2). The pod deck is back to SYMMETRIC (y±26,
//   E-stop only) — no more +y extension, no fused panel, no OLED-beside-mushroom
//   dodge. The OLED bracket holds the SSD1331 clear of the Ø40 mushroom cap.
// CABLE: E-stop NC pair + OLED SPI drop through the column grommet (Ø12, y0 z63,
//   above the trunk lip) -> the matching riser rear-wall slot -> the bay
//   (power-board NC lines + the Arduino Nano SPI). Provision; route at wiring.
// PRINT: PETG-CF (or PA6-CF), **+Z FACE DOWN** (the DECK TOP on the bed); the
//   column and its gussets rise off it. 3 walls / 20% / ~24 g. print 1.
//
// AXIS RESOLVED 2026-08-16 (#383, Aiden's call) — this line said
// "COLUMN-FACE-DOWN (the flat riser-facing face on the bed)", which names a
// FEATURE and no axis, so slice_plate.py refused the part and it sat MANUAL.
// Same failure as shoulder.scad's #259; the lesson there was that the fix has
// to land in BOTH files, because a .scad corrected on its own leaves the
// registry refusing a part that is actually decided.
//
// Measured bed-contact area for each candidate down-face, on the real STL:
//
//     +Z   1662 mm^2   37 mm tall   slenderness 0.91   <-- 4.7x the runner-up
//     -X    356          40                  2.10
//     +X    260          40                  2.46      <-- the face the old
//     +Y    198          52                  3.69          prose actually named
//     -Y    198          52                  3.69
//     -Z     75          37                  4.27
//
// The old prose pointed at the WORST-but-one face: the riser-facing column
// face is +X at 260 mm^2, against 1662 for the deck. On a warp-prone filament
// that is the whole ball game, and it is why this was worth resolving rather
// than leaving to whoever opened the slicer.
//
// THE TRADE, taken knowingly: deck-down puts the O22.6 E-stop bore MOUTH on the
// bed, so elephant-foot pinches it. Enable elephant-foot compensation, and
// check the bore takes the HB2-ES544 barrel before pressing it. The alternative
// was a 260 mm^2 footprint on a 52 mm-tall part, which risks losing the whole
// print rather than one bore mouth.
//
// NOTE: light central 4x M3 mount — the E-stop is a PALM slap, not a hammer; a
// very hard strike may flex the deck (acceptable).

$fn = 48; EPS = 0.05;
M3_CLEAR = 3.4; M2_CLEAR = 2.3;

BOSS_X   = -66.5;                  // riser pocket-boss REAR face (pod bolts here)
COL_X0   = -70.0;                  // column rear face (behind the boss)
COL_HY   = 14;                     // column half-width (clears shoulders at y15)
MOUNT    = [[-10, 61], [10, 61], [-10, 66], [10, 66]];   // (y,z) — matches riser

ES       = [-87, 0];               // E-stop panel-hole center (x,y)
ES_HOLE  = 22.6;                   // Ø22 thread + clearance
DECK_Z   = 90; DECK_T = 5;         // top deck z90..95 (E-stop mounts here)
DECK_X0  = -103; DECK_X1 = -63.35; // deck x-103..-63.35 (over the pocket)
DECK_Y0  = -26; DECK_Y1 = 26;      // deck SYMMETRIC now (OLED split off, #40)

module control_pod() {
    difference() {
        union() {
            // --- central column: bolts to the riser pocket-bosses, rises to deck
            translate([COL_X0, -COL_HY, 58])
                cube([BOSS_X - COL_X0, 2*COL_HY, DECK_Z - 58 + 1]);   // z58..91 (laps deck)
            // --- top deck (E-stop seat + OLED shelf), cantilevered over pocket ---
            translate([DECK_X0, DECK_Y0, DECK_Z])
                cube([DECK_X1 - DECK_X0, DECK_Y1 - DECK_Y0, DECK_T]);
            // --- gussets: stiffen the deck cantilever. Moved OUTBOARD to y17..21
            //     (were y10..14) to FLANK the real ~30mm E-stop contact block
            //     (y±15) hanging below — the block is wider than the old gap.
            //     (E-stop = mxuteuk 22mm 2NC, Ø40 mushroom, 77 total, ~30×48
            //     block behind the panel; specs 2026-07-08.) ---
            for (sy = [-1, 1])
                translate([DECK_X0, sy > 0 ? 17 : -21, 78])
                    cube([BOSS_X - DECK_X0, 4, DECK_Z - 78 + 1]);
        }
        // ---- mount bolt clearances (axis x, through the column into the bosses)
        for (b = MOUNT)
            translate([COL_X0 - EPS, b[0], b[1]]) rotate([0, 90, 0])
                cylinder(d = M2_CLEAR, h = BOSS_X - COL_X0 + 2*EPS);  // M2 (pinched pad)
        // ---- E-stop panel hole ----
        translate([ES[0], ES[1], DECK_Z - EPS]) cylinder(d = ES_HOLE, h = DECK_T + 2*EPS);
        // 2026-08-10 (#35): the 2x M2 heat-sets that used to sit here, at
        // x-96/-71 y23, are GONE. They existed only so oled_mount could bolt
        // to this deck edge, and oled_mount is deleted -- the OLED now mounts
        // FLAT on the rear shoulder deck (oled_tray.scad), looking up. Removing
        // them also retires a known defect: check_hole_breakout recorded both
        // bores as SUSPECT, leaving <=0.2mm of real wall on one side. This part
        // is not printed yet, so nothing drifts from a physical part.
        // ---- cable grommet: E-stop NC + OLED SPI drop into the bay (y0 z63) ----
        translate([COL_X0 - EPS, 0, 63]) rotate([0, 90, 0])
            cylinder(d = 12, h = BOSS_X - COL_X0 + 2*EPS);
    }
}

control_pod();

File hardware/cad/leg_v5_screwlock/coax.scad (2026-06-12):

// =============================================================================
// V5 Coax — LEFT, SCREW-LOCK variant
// Copy of leg_v5/coax.scad + STS3215 case mount-screw holes.
// Source shape + cavity placement unchanged; adds sts3215_mount_holes().
// =============================================================================
include <../leg_v5/leg_v5_common.scad>
include <sts3215_mount.scad>

ORIGINAL_STL = "/Users/afox/codebases/NOVA/original_body_files/SM3_Frame_LeftCoax.stl";
OVERLAY = false;

CAVITY_CENTER = [-11.6, 8, 28.8];   // Y-flipped from Right variant
CAVITY_ROT    = [90, 90, 0];

if (OVERLAY) {
    color("yellow", 0.7) import(ORIGINAL_STL, convexity = 8);
    color([1, 0, 0, 0.4]) translate(CAVITY_CENTER) rotate(CAVITY_ROT) sts3215_cavity();
    color([0, 0, 1, 0.6]) translate(CAVITY_CENTER) rotate(CAVITY_ROT) sts3215_mount_holes();
} else {
    difference() {
        import(ORIGINAL_STL, convexity = 8);
        translate(CAVITY_CENTER) rotate(CAVITY_ROT) sts3215_cavity();
        translate(CAVITY_CENTER) rotate(CAVITY_ROT) sts3215_mount_holes();
    }
}

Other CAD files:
ros2_ws/src/nova_description/meshes/SM3_Foot.stl
hardware/cad/chassis/trunk.stl
hardware/cad/leg_v6/coax_L.stl
hardware/cad/leg_v5_screwlock/coax_R.scad
hardware/cad/archive/leg_v2/Leg-V2-Assembly.step
hardware/cad/archive/leg_v3/coax_v31_cover.step
hardware/cad/archive/leg_v3/coax_v31_cover_L.step
hardware/cad/archive/leg_v3/coax_v31_cover_L.stl
hardware/cad/archive/leg_v3/coax_v31_cover_R.step
hardware/cad/archive/leg_v3/coax_v31_cover_R.stl
hardware/cad/archive/leg_v3/coax_v31_shell.step
hardware/cad/archive/leg_v3/coax_v31_shell_L.step
hardware/cad/archive/leg_v3/coax_v31_shell_L.stl
hardware/cad/archive/leg_v3/coax_v31_shell_R.step
hardware/cad/archive/leg_v3/coax_v31_shell_R.stl
hardware/cad/archive/leg_v3/femur_v31_cover.step
hardware/cad/archive/leg_v3/femur_v31_cover_L.step
hardware/cad/archive/leg_v3/femur_v31_cover_L.stl
hardware/cad/archive/leg_v3/femur_v31_cover_R.step
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

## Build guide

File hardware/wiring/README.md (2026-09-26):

# Wiring Diagrams

Power rail map and signal/data wiring for the as-built robot. Refer to BOM v3.4 + `hardware/pcb-mods/README.md` (PCB v6 spec) + `docs/power-budget.md` (current math) for source-of-truth values.

## Power chain (4S LiPo → 4 active rails + 1 reserved)

```
                              ┌─── MRBF-30 terminal fuse (Blue Sea 5191 block, 30A / 58V DC)
                              │
4S LiPo 14.8V (12.8-16.8V) ──┼── MOSFET reverse-polarity protection
   (Ovonic 6000 mAh × 2)     │
                              ├── E-stop NC (Mxuteuk HB2-ES544, 22 mm latching)
                              │        │ kills leg + hip + L2 + arm EN (EN_BUCKS)
                              │        │ Jetson rail stays live for debug
                              │        │ 2nd NC contact block → J21 → SafetyFSM (below)
                              │
                              ├── SW1 master rocker (Blue Sea 8282 Contura, ~18 A,
                              │        front-shoulder panel — VBAT → VBAT_PROTECTED;
                              │        LIT: lamp on the LOAD side, ground via SW2.1)
                              │
                              ├── MOSFET hard-cutoff @ ~12.56V measured (comparator-driven)
                              │        → corrected 2026-09-25 (#432): 12.42 V falling /
                              │          12.70 V rising, expected; 12.56 is the no-hyst midpoint
                              │
                              └─┬─ Pololu D42V110F7  → 7.5V/10A → leg rail
                                │                                 (8× STS3215 19kg femur/tibia)
                                │                                 ★ 4× XT30 star injection
                                │                                 1000 µF / 25V bulk cap at each
                                │                                 2× SMBJ8.5A TVS across injections
                                │
                                ├─ Pololu D42V110F12 → 12V/9A   → hip rail
                                │                                 (4× STS3215 30kg ONLY)
                                │                                 XT30 injection at chassis floor
                                │                                 SMBJ13A TVS across injection
                                │
                                ├─ Pololu D24V22F12  → 12V/2.6A → L2 LiDAR (dedicated)
                                │                                 LC filter on output:
                                │                                 22 µH choke + 470 µF / 25V cap
                                │
                                ├─ Pololu D42V55F12  → 12V/~3A  → Jetson barrel jack (5.5 × 2.5)
                                │
                                ├─ [reserved D42V55F7] → 7.5V → arm rail (Phase 4 unstuffed)
                                │
                                └─ UBEC 5V/5A        → V5_AUX 5V → the ENTIRE safety chain
                                                                  (LM393s + trip VREFs), logic
                                                                  board, OLED/LED, M1 voltmeter,
                                                                  SW1 lamp — see the 🔴 below
```

⚠️ **The tree understates two things.** (1) The E-stop and the hard-cutoff are NOT series
elements in the battery feed — both act by pulling buck **EN** pins low (`EN_BUCKS`/`EN_JET`);
the feed itself is only ever broken by the fuse, Q1 and SW1. (2) **The UBEC is deliberately
NOT killed by either** — it has no EN, so `V5_AUX` stays up through a hardcut, which is what
keeps the comparators latched. The one thing that kills it is SW1 (or the pack). ⚠ superseded by ../../docs/power-chain-fmea.md#pc-07 (not latched: 0.28 V hysteresis only)

### Regen TVS clamps (harness parts — not on either PCB)

E-stop pressed mid-gait disables the bucks (output high-Z, can no longer sink regen to the
battery) while the legs keep coasting and generating — the only sink left is the bulk caps,
and 1 J into ~5000 µF from the 7.5 V leg rail works out to roughly 21 V against 25 V-rated
caps. Normal-operation regen is already safe (the Pololu bucks are synchronous and sink
current back to the battery while enabled); the clamp only matters during the disable/e-stop
window. Order source: `docs/order-list.md:33,58-59,249-256`.

| Injection | TVS part | Qty | Standoff / clamp (datasheet) |
|---|---|---|---|
| V7V5_LEG XT30s (leg rail) | SMBJ8.5A | 2 | 8.5 V standoff, 14.4 V max clamping voltage (`V_C` at rated `I_PPM`) |
| V12_HIP XT30 (hip rail) | SMBJ13A | 1 | 13 V standoff, 21.5 V max clamping voltage |
| V12_L2 XT30 (optional) | SMBJ13A | 1 (optional) | same as above |

These clamps protect the 25 V bulk caps only — they do not protect the STS3215 servos: the
leg-rail STS3215s (7.4 V variant, 19 kg) have an absolute max of 8.4 V (`docs/setup-servos.md:92`,
`BOM.md:64`), and the SMBJ8.5A's 14.4 V max clamping voltage is well above that, so servo
exposure during an e-stop regen event is unquantified and needs a scope capture (same
instrument gap as #244).

Numbers above are from the Vishay `SMBJ5.0A thru SMBJ188A` TransZorb datasheet (doc #88392,
rev 09-Jan-2024), electrical characteristics table: SMBJ8.5A row (V_BR 9.44–10.4 V, V_C
14.4 V), SMBJ13A row (V_BR 14.4–15.9 V, V_C 21.5 V). Both standoff voltages sit above their
rail's nominal voltage (8.5 V > 7.5 V leg rail, 13 V > 12 V hip rail — required so the TVS
doesn't conduct in normal operation), and both clamping voltages land safely under the 25 V
cap rating, which is the point of installing them.

**Install (per injection pigtail, unidirectional, all parts):** solder across the XT30
pigtail on the **servo side** of the connector (downstream of the injection point, closest to
what's generating), **cathode (banded end) to +, anode to GND**. Heat-shrink over the joint —
same idiom as every other XT/fuse joint (`docs/master-bom.md` harness-consumables table).

## Safety chain trip points (highest pack voltage first)

| Trip | Pack V | Cell V | Action |
|---|---|---|---|
| 1 | 13.2 V | 3.30 V/cell | 608AC charger LVC alarm (user-facing beep) |
| 2 | ~~13.0 V~~ ~~**13.03 V measured-parts**~~ **12.96 V falling / 13.06 V rising (expected, #432)** | ~~3.26~~ 3.24 V/cell falling | LM393 comparator → Teensy GPIO **pin 4** → `/battery_low` Bool → Jetson `systemctl poweroff` (clean SD unmount). ~30-60 s window. |
| 3 | ~~12.4 V~~ ~~**12.56 V measured-parts**~~ **12.42 V falling / 12.70 V rising (expected, #432)** | ~~3.14~~ 3.10 V/cell falling | Second LM393 stage → **BSS138 (Q2) pulls EN_BUCKS low → all bucks off** (leg/hip/L2/arm); Q4 also kills Jetson EN. Autonomous backstop. (Q1 IRLB3034 = reverse-polarity protection, separate — does NOT break the battery feed.) |
| — | — | — | E-stop (manual, SW2 NC) — pulls EN_BUCKS low via Q3 → kills leg + hip + L2 + **arm** buck EN. Jetson stays alive. **Needs `V5_AUX` up** (#430 — see below). |
| — | — | — | E-stop (manual, J21 2nd NC) — same button press, tells software: contact opens → Teensy pin 5 reads HIGH (fail-safe) → `SafetyFSM` latches e-stop state, which is what preflight's estop check reads. Does not itself de-energize anything. |

⚠️ **The HB2-ES544 needs TWO separate NC contact blocks** — one per path above. SW2 is the
hardware kill (button → Q3 → EN_BUCKS, de-energizes the bucks ~~regardless of firmware~~ **→ corrected
2026-09-25, #430: independent of firmware, but only while `V5_AUX` is up.** Pressing SW2 lets
`R13` 10k pull Q3's gate up to `V5_AUX`, and R13 is the only pull-up on that gate (board file).
With the UBEC dead or unplugged, Q3 stays off and the bucks keep running with the button
pressed. Bench step: the E-stop section of "As-built switch wiring" below, and
`docs/pre-power-on-validation.md` §3 step 5. v7 fix in `hardware/pcb-mods/BUILD_PLAN.md` §8); J21 is
the software sense (button → Teensy → `SafetyFSM`, no power path). They are electrically
independent so either one failing doesn't silently take out the other, but that also means
both must be wired and both must change state on the same press — see harness row below and
the continuity check in `docs/pre-power-on-validation.md`.

⚠️ **Rows 2–3 carry the MEASURED-parts predictions (2026-08-08): 13.03 / 12.56 V** — the
fitted divider is 0.1794 (R2 99.7k / R3 21.8k) against the UBEC's measured 4.98 V.
`pre-power-on-validation.md` §2 states it outright: *expect 13.03 / 12.56, NOT 13.0 / 12.4* —
metering against the old nominals at bring-up would flag a correct board. The nominals are
struck, not deleted, per house style.
**→ corrected 2026-09-25, #432:** 13.03 / 12.56 is the no-hysteresis midpoint. In normal running
both comparator outputs are LOW, so `R15` 1M and `R14` 470k pull the references down. The trips
a discharging pack actually crosses are **12.96 V (`BATT_LOW`) and 12.42 V (`HARDCUT`)**. They
release on the way back up at **13.06 / 12.70 V**. All four are expected values, pending the
two-direction sweep in `pre-power-on-validation.md` §2, where the arithmetic is.

### 🔴 The whole low-voltage cutoff dies with `V5_AUX` — and that is what the buzzer is for

Every element of the table above is powered from **`V5_AUX`, the 5 V UBEC**. If it fails:

- both LM393 comparators are unpowered,
- the pull-ups on `BATT_LOW` / `HARDCUT` go with it, and
- **both references disappear** — `VREF_G` and `VREF_H` are divided down *from `V5_AUX`*
  (`R4` 11.3k / `R6` 12.1k), so there is nothing left to compare against.

Result: **no 13.0 V warning, no 12.4 V hard cut, and the pack over-discharges with nothing
in the robot able to stop it.** Single point of failure for the entire electrical
protection chain, and it fails silently — a dead UBEC looks like "the aux rail is down",
not like "the battery is now unprotected".

**The mitigation already exists and is already owned:** the FLY-RC balance-plug buzzer
(3.3 V/cell, `master-bom.md`). It is powered from the balance leads, so it is genuinely
independent of `V5_AUX`, the board, and the firmware.

⚠️ **Keep it plugged in whenever the pack is in the robot.** `order-list.md:222` calls it
"an independent last line" without saying what it is independent *of* — this is what.
Treating it as optional belt-and-braces removes the only remaining protection in exactly
the failure case it exists for.

*Source: 2026-06-17 safety-chain circuit-logic review. The review lived on branch
`docs/status-b1-done` and never reached main; recovered 2026-08-15.*

## Feetech TTL bus (single-ended half-duplex, 1 Mbps default)

```
Teensy 4.1                    SN74LVC125A (quad tri-state buffer)         Bus pad
  Serial1 TX (pin 1) ─────────► gate1 input                           ┐
  Serial1 RX (pin 0) ◄───────── gate2 output                          │
  OE̅_TX (pin 2, active-LOW) ──► gate1 enable (LOW = drive TX → bus)    │
  OE̅_RX (pin 3, active-LOW) ──► gate2 enable (LOW = listen bus → RX)   ▼
                                                       12× STS3215 daisy chain
                                                       PER-LEG SEQ (ID = chain order):
                                                       FL 1-3 · FR 4-6 · RL 7-9 · RR 10-12
                                                       leg = haa,hfe,kfe — haa(1,4,7,10)=12V,
                                                       hfe/kfe=7.5V (see joint_id_map.yaml)
                                                       IDs 13-18 reserved (Phase 4 arm)

JP_BUS_MASTER — ~~solder bridge~~ a 3-pin header + SPC02SYAN shorting shunt
(the "solder bridge" wording predates the fitted part):
  2–3 = B (Teensy → SN74LVC125A → bus) — **FITTED and verified 2026-08-09**
  1–2 = A (FE-URT-1 → bus, for ID assignment + bench debug)
```
> Source of truth for these pins = `firmware/teensy/firmware/src/main.cpp` (Serial1 0/1, OE̅ 2/3) + the `nova_pcb_v6_logic` netlist.

**Bus integrity footprints on PCB v6 (populate per measured error rate):**
- Series R (22 Ω, R1 0603) + ferrite (FB1) at SN74LVC125A output — slope rate-limiting / EMI
- Ferrite bead at each servo entry — common-mode noise rejection
- Star-ground reference — **implemented by the solid GND.Cu inner plane** (single low-Z return; the plane supersedes a literal star for this single-ended TTL bus — no separate star wiring at FE-URT-1)
- **NOT** 120 Ω differential termination — Feetech bus is single-ended TTL, not RS-485

**Cable plan:** Feetech daisy-chain cables (ordered), one ferrite bead per servo entry (footprint on PCB), GND-plane reference (the GND.Cu plane is the single low-Z return — see above). If errors persist after populating: drop baud 1M → 500k → 250k.

**⚠️ DUAL-VOLTAGE BUS — VCC-isolated boundary links (FRY-CRITICAL, added 2026-06-22):**
ONE shared signal, TWO power voltages. Under the per-leg-sequential ID map, **each haa (hip) = 12V (IDs 1,4,7,10); each hfe/kfe = 7.5V**. The chain runs haa→hfe→kfe per leg, so 12V↔7.5V transitions occur BOTH within a leg (haa→hfe) AND between legs (kfe→next leg's haa). A stock 3-wire Feetech cable carries GND+VCC+Signal — daisy a 12V servo straight to a 7.5V servo and the VCC wire bridges 12V↔7.5V → short / fried servo.

Required harness:
- **Power injected per voltage segment:** 12V to hips (V12_HIP), 7.5V to femur/tibia (V7V5_LEG star injection). Every servo's VCC pin must see its correct rail.
- **At every 12V↔7.5V transition** — haa→hfe WITHIN each leg (×4) AND kfe→next-haa BETWEEN legs (×3) = **7 boundaries** (the earlier "4 hip→femur" undercounted the 3 between-leg ones): use a **SIGNAL+GND-only link (VCC pin pulled/cut)**. Simplest + safest: make **ALL inter-servo cables signal+GND-only** and inject each servo's VCC locally from its rail — then there's no boundary to miscount. NO stock 3-wire cable across a voltage boundary.
- **Meter-verify every servo VCC = its correct rail (7.5 vs 12V) BEFORE the chain sees power.** #1 fry path on the build (pre-power-on §1c).

**Per-link build recipe (how a servo gets power when no cable carries VCC servo-to-servo):**
The STS3215's two 3-pin ports are internally paralleled (all 3 pins bussed straight through), and
the servo doesn't know where each wire came from — power and signal merge **in the connector**, not
on the servo. Each servo-side plug is assembled from three sources:

| pin | comes from |
|---|---|
| VCC | spur off the servo's **local XT30 injection** — 7.5V (J3–J6) for hfe/kfe, 12V (J7) for haa |
| GND | common star ground — **AND kept continuous through every daisy link** (it's both power return and the data line's signal reference; GND following the signal wire = less noise) |
| Data | daisy chain from the previous servo (chain entry = J8 pin 3) |

Steps per link: stock Feetech 3-wire cable → **pull the VCC pin from the upstream end** → crimp the
XT30-fed VCC branch into the servo-side housing. Result: signal path unbroken J8→servo1→…→servo12,
power a star from the XT30s, and a 12V↔7.5V boundary is physically impossible to miscount.

⚠️ **Each local XT30 injection carries a TVS clamp** (SMBJ8.5A on the 7.5V/leg injections,
SMBJ13A on the 12V/hip injection) — soldered across the pigtail on the servo side, cathode
(band) to +, heat-shrunk. See "Regen TVS clamps" above for parts, install, and why. Do this
before crimping the VCC branch into the servo-side housing, not after.

**Connector housings — don't mix:** servo ports are **Molex 5264-style 2.54mm** (Feetech standard);
**JST-XH is the board side only** (J8 pigtail). Don't crimp XH housings for servo ends. Chain entry
from J8 uses **GND + Signal only** — J8's VCC pin (V7V5_LEG) feeds nothing under this plan.

Cables still needed: **extension daisy cables for long leg runs** (~~the ⬜ master-bom item never received~~ **re-ordered 2026-07-11, 2× waveshare 5264 kits, arr ~Jul 13 — confirm in hand at the bench**, `master-bom.md` #55) + the **VCC-isolated boundary jumpers** (make by pulling the VCC pin from a stock cable).

**Cable length:** ~2 m total harness. Community reports 12 m / 8 axes workable, so 2 m / 12 nodes is well within margin.

## INA226 telemetry topology

```
Teensy 4.1                          I²C bus (separate from Arduino Nano aux bus)
  SDA (pin 18) ──┬────────────────┬────────────────┬────────────────┐
  SCL (pin 19) ──┤                │                │                │
                 ▼                ▼                ▼                ▼
            INA226 0x40       INA226 0x41       INA226 0x44       INA226 0x45
            leg 7.5V          hip 12V           Jetson 12V        L2 12V
            shunt: 2 mΩ       shunt: 2 mΩ       shunt: 2 mΩ       shunt: 2 mΩ
            GODIY 20A R002 modules (all 4) — firmware setMaxCurrentShunt(20, 0.002)

  → /power_rails Float32MultiArray @ 10 Hz — **12 floats** (9 was stale; #349):
                                             [leg_v, leg_a, leg_w,
                                              hip_v, hip_a, hip_w,
                                              jetson_v, jetson_a, jetson_w,
                                              l2_v, l2_a, l2_w]
```

**Current-sense wiring (CRITICAL — PCB carries NO shunt; R13/R14 deleted):** the INA226 reads current only if the rail flows through its onboard 2 mΩ shunt (IN+→IN−). The board exposes just I²C+power; IN+/IN− are the module's **screw terminals** → wire **inline in the harness**: rail source → IN+ → shunt → IN− → load. ⚠ superseded by ../../docs/power-chain-fmea.md (R13/R14 designators were reused: R13 = e-stop pull-up, R14 = hardcut hysteresis — both live)
- **Hip (0x41 @ J7) / Jetson (0x44 @ J12) / L2 (0x45 @ J13):** single XT30 injection → insert the module there → full rail current. ✓
- **Leg (0x40):** rail stars into **4× XT30 (J3–J6) on the PCB** → no single point carries total leg current. **DECISION 2026-06-26: DEFERRED (not needed for v1).** ⚠️ Leg INA reads **nothing** unless IN−/VBUS is **tapped to the leg rail** at assembly (board wires only I²C+power; IN± = module screw terminals, VBUS tied to IN−): **tap IN− → `leg_v` valid, `leg_a` invalid** (no inline shunt) = voltage-only; **leave IN− unwired → BOTH `leg_v` and `leg_a` invalid** (not just current). Total leg current has no clean inline point (4× XT30 star) regardless. Leg stall/over-current is covered by **per-servo STS3215 load** (`effort[]` on the bus); hip/Jetson INA cover rail current. Adding total-leg sense (RAW/clean split + sense-loop connector at U1 VOUT) is a **v7-rev** item only if board-level total-leg-power logging is ever wanted — see scope in chat 2026-06-26.

**4th INA (0x45):** v1 → **L2 rail** (matches firmware `INA226_ADDR_L2`; enable `-D NOVA_INA226_L2`). L2 monitoring is *optional* (low-power dedicated rail, alive from its data stream) but you have the module → use it. **Arm rail (Phase-4)** is margin-thin (0.83× peak) → it wants its own INA: add a **5th off-board module at 0x46** when the arm goes in (no board change — taps the same I²C bus). The board's `U12 = arm` label is Phase-4-aspirational; for v1 wire U12's shunt into the **L2** rail.

I²C pull-ups: **4.7 kΩ** to 3.3 V on SDA + SCL (R11/R12 on the power board, near the INA226s).

## Arduino Nano peripheral map (reduced per BOM v3.5 cut)

No I²C aux bus anymore. PIR / ultrasonic / DFPlayer / MPU-6050 dropped
because D456 + L2 perception stack covers their roles. Nano's only job
is to drive the OLED + LED strip from data received over USB-serial from
the Jetson.

```
Jetson ──USB-serial (115200)──► Arduino Nano
                                  │
                                  ├──SPI──► SSD1331 96×64 OLED
                                  │         (MOSI D11, SCK D13, CS D10,
                                  │          DC D9, RST D8)
                                  │
                                  └──GPIO──► WS2812B RGB LED strip
                                            (data D6, 800 kHz)
```

Power: 5 V from UBEC rail. ~0.3 A combined (OLED + 4 LEDs at moderate
brightness).

## USB topology (Jetson Orin Nano Super, P3766)

| Port | Cable | Device | Notes |
|---|---|---|---|
| USB 3.1 (blue, USB-A) | USB 3.1 shielded | Intel RealSense D456 | Color + Depth + IMU (~2-3 W streaming) |
| USB-A | USB-A → micro-USB | Teensy 4.1 | micro-ROS over USB-CDC, agent at `/dev/ttyACM0` |
| USB-A | USB-A → USB-mini | FE-URT-1 | Bench-only (Pattern A fallback for ID setup) |
| USB-C UFP | (optional) | Mac host | Serial console + l4tbr0 USB-C bridge (warning: hijacks default route — see `docs/setup-network.md` Gotcha 2) |

## Ethernet topology

Point-to-point, no switch on the robot (decision 2026-08-14):

```
Unitree L2 LiDAR
  IP: 192.168.1.62  ──Cat 6 (direct)───  Jetson Orin Nano enP8p1s0
  UDP target: 6101                       192.168.1.2/24 (static via nmcli
                                          connection nova-lan)
```

Cable: Cable Matters 10 Gbps snagless Cat 6 (1 ft) × 1, on-robot.

The 5-port unmanaged gigabit switch (TP-Link LS105G or NETGEAR GS305) is
**bench-only** — not mounted on the robot. It stays around so a dev laptop can
join the LAN on the bench when wanted. On-robot dev access is Jetson's
built-in WiFi.

## Wire gauge convention

| Wire | Gauge | Use |
|---|---|-----|
| 18 AWG silicone | 18 AWG | Servo power (7.5 V + 12 V rails), battery feed to bucks — per-station U1–U5 landings only (each ≤ ~6 A input) |
| 12 AWG silicone | 12 AWG | Pack pigtail → MRBF-30 (Blue Sea 5191 block) → J1 XT60 — the summed ~14-15 A sustained / 25-30 A transient path the 30 A fuse protects; 5/16" (M8) 12-10 AWG ring lugs at the 5191 stud (`docs/master-bom.md:228,231`) |
| 22 AWG hookup | 22 AWG | Signal-level (INA226 I²C, comparator outputs, E-stop pairs (incl. J21 GPIO sense), buck EN, SW1 lamp ground, RGB LED data) |
| Feetech TTL daisy-chain | 28 AWG (vendor) | Servo bus signal + power passthrough **within one voltage segment only** (see dual-voltage note — no power across 12V↔7.5V boundary) |

## Color code

- **Red:** +V (positive supply, all voltages) — and where BOTH legs of a switch are
  positive, red goes to the leg that is **always hot** (see White)
- **White:** the SWITCHED positive leg when its partner is always-hot — as built on
  `SW1` (white = load/`VBAT_PROTECTED`, red = supply/`VBAT`). The colour exists so the
  always-live conductor is unambiguous with the switch off
- **Black:** GND (common)
- **Yellow:** signal (logic-level, GPIO)
- **Green:** I²C SDA / SCL (preserve white-on-green if available)
- **Blue:** UART data
- **Orange:** safety (E-stop, comparator output)

## Header wiring — insulation and clearance at `M1` / `J2`

Added 2026-08-13, after the flying leads on both headers were soldered. Nothing in
this repo covered it: the section below is mechanical *routing*, and `BUILD_PLAN.md`
covers what to solder, not what the wire does after the joint cools.

`M1` (pack-voltage tap) and `J2` (UBEC aux tap) are the only 2.54 mm headers carrying
**raw pack voltage next to GND**. Pad nets read out of
`../pcb-mods/nova_pcb_v6_power_v2/nova_pcb_v6_power_v2.kicad_pcb`:

| pair | gap | if they touch |
|---|---|---|
| `M1`.1 `VBAT_PROTECTED` ↔ `M1`.2 `GND` | **2.54 mm** | dead short across the pack |
| `J2`.1 `VBAT_PROTECTED` ↔ `J2`.2 `GND` | **2.54 mm** | dead short across the pack |
| `J2`.2 `GND` ↔ `J2`.3 `V5_AUX` | **2.54 mm** | shorts the UBEC output |
| **`J2`.1 `VBAT_PROTECTED` ↔ `J2`.3 `V5_AUX`** | **5.08 mm** | **16.8 V onto the 5 V rail** |

**The last one is the expensive one, and it is not obvious from the board.** `V5_AUX`
is the *only* supply for every active part on the logic board — traced from
`nova_pcb_v6_logic.kicad_pcb`:

| pad | part | why 16.8 V kills it |
|---|---|---|
| `U6`.1 | **Teensy 4.1 VIN** | 5.5 V absolute max. It is the Teensy's only 5 V input, and its regulated `T3V3` is what sources `+3V3` for `U7` — which is also why `BUILD_PLAN.md` §7 says cut the `VUSB`↔`VIN` pad before seating it |
| `U12`.27 | **Nano 5V pin** | bypasses the Nano's regulator and lands on the ATmega VCC directly. Confirmed by the netlist: pad 30 is `unconnected-(U12-VIN-Pad30)`, so the board feeds 5V, not VIN |
| `J10`.2 | SSD1331 OLED | 5 V module |
| `J11`.1 | WS2812B strip | 5 V module |

One contact kills all four at once, and nothing announces it until power-up.

A short across the pack clears through the off-board MRBF-30, but that is hundreds of
amps for the milliseconds before it opens, through 22 AWG, with `Q1` carrying the fault.

⚠️ `J2` is also the most crowded joint on the board — **four wires into three holes**,
because the SoloGood UBEC has separate input and output grounds that common at `J2`.2.
See `../../docs/order-list.md` §"Wiring to `J2`".

Note `SW1` sits between `VBAT` and `VBAT_PROTECTED`, so all of this is dead with the
rocker off. That is not a mitigation — the exposure is every minute the robot runs.

### Insulation doctrine

1. **Heatshrink is primary.** Ginsco assortment, `../../docs/master-bom.md:232`, which
   already specs it for "every XT / TVS / fuse joint" — this is that class of joint.
   Slide the sleeve on **before** soldering, park it up the wire, solder, trim flush,
   then bring it down over the joint. Doing it after means you cannot get a sleeve on
   without desoldering.
2. **Kapton is for zones a sleeve cannot reach**, not for whole joints. Its silicone
   adhesive lifts off round surfaces under vibration and thermal cycling, it gives no
   strain relief, and a lifted edge re-exposes the joint silently. As a patch on an
   already-soldered joint, or laid flat over the top of a header as a barrier against
   something landing on it from above, it is the right tool.
3. **On a 3-way header, wrap the MIDDLE pin.** One wrap on `J2`.2 blocks both `1↔2`
   and `2↔3`, and leaves only the widest pair (`1↔3`, 5.08 mm) with a wrapped conductor
   physically between them. Cheapest coverage per wrap. Done on the build board
   2026-08-13.
4. **Exposed conductor between the shrink and the joint is an electrical non-issue and
   a mechanical one.** Air breaks down near 3 kV/mm, so 2.54 mm against 16.8 V has
   about five orders of margin — nothing jumps that gap. But shrink that stops short
   leaves the bare zone at the **pin base**, which is exactly where the two conductors
   are closest; further up the wires diverge. Close it with Kapton if it is more than a
   millimetre or so.
5. **Dress both harnesses outward in −y at the joint** — see the clearance note below.

### The logic board overhangs both headers

Both boards share one coordinate frame (`H1`–`H4` at x 103/177, y 63/129 on each), and
the logic board's outline overhangs its own mounting holes by **6.00 mm** in −y — its
Edge.Cuts run y 57.00–135.00 against holes at 63/129. So **the logic board's near edge
lands at y = 57.00**, and that edge crosses between pin 1 and pin 2 of both headers:

| pad | y | vs the logic-board edge |
|---|---|---|
| `M1`.1 | 55.00 | 2.00 mm clear |
| `M1`.2 | 57.54 | **0.54 mm under** |
| `J2`.1 | 56.00 | 1.00 mm clear |
| `J2`.2 | 58.54 | **1.54 mm under** |
| `J2`.3 | 61.08 | **4.08 mm under** |

Consequences:

- **Route the bundles away in −y.** Pin 1 of each is already outside the footprint, so
  bending outward at the joint is the natural direction and keeps nothing standing up
  under the overhang.
- **Height is not the constraint** — M3×20 standoffs give a 20 mm gap, and a soldered
  joint with shrink lying flat is ~1.4 mm. A 2.54 mm connector housing would sit
  ~6–8 mm up *plus* bend radius for a 20 AWG lead, and cramped bends side-load a
  friction-fit housing off its pins. Soldered and dressed flat is the better fit here.
- **Access closes when the mezzanine does.** Neither joint is reachable with the logic
  board mounted. Everything that needs to touch them — the check below,
  `../../docs/pre-power-on-validation.md` — happens at stage 9, before stage 10 fits the
  modules.

### The short check, and why it gets harder later

Board-only path from `VBAT_PROTECTED` to `GND` before stage 9 is `R2` → `VSENSE` → `R3`.
From the parts as measured 2026-08-02 (99.7k + 21.8k) that is **≈121.5k**, at both
`M1`.1↔`M1`.2 and `J2`.1↔`J2`.2. Nothing else bridges those nets yet — `C8`/`C9`, `Q1`,
the bucks and the XT30s are all stage 8–9.

**Take this reading before stage 9.** Once ~5470 µF lands on the rail, every measurement
on that net behaves like the one that already misled this build once: `J2`.1↔`J2`.3 read
as a dead short and was an uncharged cap.

With the UBEC and the voltmeter still attached you will not see a clean 121.5k — both
modules parallel their own input impedance across it. **Chase the shape, not the number:**

- Near-zero, *instantly*, same value in **both probe polarities**, and it stays there →
  a real short. A real short is boring.
- Starts low and climbs, or settles up in the tens or hundreds of k → that is the
  modules and their input caps, not a fault.

### 🔴 IT HAPPENED — `M1` shorted `VBAT_PROTECTED` to GND, 2026-08-14

Everything above was written as a *predicted* hazard on 2026-08-13. It materialised the
next day, on `M1`, at exactly the pair and the spacing this section names. Recording the
signature so the next occurrence is a number to match rather than a hunt.

**The tell was not on the shorted net.** It surfaced while checking `Q1`:

    BATT_NEG ↔ GND    measured 109.6k, symmetric in both probe polarities

`R_gs1` (100k) + `R17` (10k) = 110k, and those are the only resistive path from
`BATT_NEG` to the `VBAT_PROTECTED` node. Reading 109.6k means the rail on the far side of
`R17` was sitting at ~0 Ω to GND. It should have read **121.5k + 110k ≈ 232k**. A rail
short showed up as a *plausible-looking* two-resistor reading somewhere else entirely.

**Confirmed by removal**, which is the only proof that settles it: `M1` snapped off during
probing, and `VBAT_PROTECTED`↔GND went straight back to a slow climb settling on
**~121.5k** — `R2` + `R3`, exactly the fixed divider, with no short and the trip divider
intact.

**Cause: `M1` was the one header that never got insulated.** `J2`'s middle pin had been
Kapton-wrapped the day before (one wrap covering `1↔2` and `2↔3`, per the doctrine above);
`M1` had the same 1.4 mm of exposed conductor at the pin base and got nothing. The
mitigation was applied to one of the two headers this section names and not the other, and
the uninsulated one is the one that shorted. Same shape as
[[fixed-the-instance-not-the-convention]], in solder.

**Three false leads, all of which cost time — expect them:**

1. **`0.L` at `M1`.1↔`M1`.2 read as an open circuit.** It was the probe sitting on
   heatshrink. An insulated joint reads OL every time; probe bare metal or a screw
   terminal (`SW1`.2 is the easiest on this board).
2. **Inferring the rail through `R_gs1`+`R17` has ~1 kΩ of resolution.** "≈0 Ω" could not
   distinguish a solder bridge (<1 Ω) from an active module's front end (hundreds of Ω).
   Measure the pair *directly* — 0.1 Ω resolution instead of arithmetic on two 100k-class
   parts.
3. **Visual inspection found nothing.** It never does at this spacing; the metal that
   matters is at the pin base under the sleeve. The meter found it, the eye did not.

**And the reason the deadline in this section is real:** this was caught with the rail
still simple. One stage later, ~5470 µF of electrolytic would have made the same 0.2 Ω
indistinguishable from a charging cap — and a 4S pack into a shorted `VBAT_PROTECTED`
dumps through the MRBF-30, `Q1` and the plane.

## As-built switch wiring (2026-08-16) — SW1 done and proven, e-stop landed, checks OWED

### SW1 — Blue Sea 8282 Contura (LIT — three wires, poles NOT interchangeable)

The rocker has **3 spades**; the third is the lamp (reads **1.9 V** in diode mode). With
the rocker OFF the LED path runs to the **load** pole → the lamp is internally tied to
the LOAD terminal. **Swap supply/load and the lamp ties to `VBAT` upstream of the
switch — lit whenever the pack is in, switch off included** (parasitic drain, lying
indicator). Identify spades by meter, not moulded numbers: the pair that goes OL → 0 Ω
across the throw is supply+load; the survivor is the lamp.

| wire | spade | lands at | net |
|---|---|---|---|
| **red** 18 AWG | supply (no LED path) | `SW1`.1 | `VBAT` — **always hot** |
| **white** 18 AWG | load (LED pole) | `SW1`.2 | `VBAT_PROTECTED` |
| **black** 22 AWG | lamp | **`SW2`.1** | `GND` (~20 mA) |

⬜ verify: the lamp is fed from `VBAT_PROTECTED` (up to 16.8 V at full charge) — the Blue Sea
8282's lamp rating vs that must be confirmed from the primary datasheet (secondary listings
say 12 V/24 V dual-rated, primary site was unreachable).

⛔ Lamp ground is **NOT** `J2`.2/`M1`.2 (the clearance-hazard headers above — where the
M1 short actually happened) and **NOT** `J1`.1 (`BATT_NEG`, routes lamp current around Q1).

✅ **Supply + load VERIFIED 2026-08-16**: `J1`.2 ↔ a `VBAT_PROTECTED` pad across the
throw — OFF = OL, ON = ~0 Ω. One probe pair crosses both ferrules, both spade joints
and the contacts.

**Ferrules on every screw-terminal end** (crimps owned): 18 AWG → 0.75/1.0 mm²,
22 AWG → 0.34/0.5 mm². Never solder AND ferrule; spade ends still solder. `SW2`.1
carries **two** conductors (orange e-stop return + black lamp ground) → twin ferrule,
or twist both under one 0.75 mm². A stray strand at `SW1` bypasses the master switch
silently; at `SW2` it holds the e-stop in RUN forever — that is why these blocks
get ferrules.

### E-stop — Mxuteuk HB2-ES544, TWO INDEPENDENT NC paths, 4× 22 AWG × 250 mm

Block A → power `SW2` (`GND`/`EN_SW` — the hardware kill, works with firmware dead
**but not with `V5_AUX` dead**, #430).
Block B → logic `J21` (pin 1 → Teensy pin 5 sense, pin 2 → GND). **Never series or
parallel the blocks.** NC identified per block (released ~0 Ω / latched OL) — "2NC"
parts ship with mixed blocks, check both. `SW2` is a dry contact: either orange on
either pad, **but both must come from the SAME block** — one-from-each looks identical
and voids the independence. `J21`: soldered direct to the pins, individual heat-shrink
(same call as `J2`/`M1`); the 250 mm slack is what lets the logic board lift off its
standoffs without unplugging.

### ⏳ The verify table — SPECIFIED, NOT YET RUN as of 2026-08-28

| probe | released | latched |
|---|---|---|
| `SW2`.2 ↔ `J20`.3 (GND) | **~0 Ω** | **~12.9 k** |
| `J21`.1 ↔ `J21`.2 | **~0 Ω** | **OL** |
| `SW2` pair ↔ `J21` pair | **OL** | **OL** |

12.9 k is computed with its own cross-check: R13 10k + the 2.9 k `V5_AUX`↔GND leg
(same probe read 19.83 k at stage 2, pre-UBEC = 10 + 9.83; the UBEC dropped the leg to
2.9). 19.8 k now = the UBEC has come off; 10 k flat = the ground leg is not landing.
The 0 Ω ↔ 12.9 k swing IS the e-stop function test. Row 3 is the one that catches
crossed blocks — the failure rows 1–2 cannot see. Also owed: the lamp-ground run
itself, the powered lamp check (pack in, SW1 OFF → **dark**; lit = red/white swapped),
the diode-mode orientation on the lamp spade (cathode-vs-anode — wrong guess = dark
lamp, harmless), and a TPU `cable_clip` anchor within ~50 mm of the board on each
bundle.

**Powered torque-cut test. Owed. Run it TWICE (#430, added 2026-09-25).** The table above is
unpowered continuity. The real test is powered, per `docs/pre-power-on-validation.md` §3 step 5:
bucks running, press → the `EN_BUCKS` rails (`U1`–`U3`) die and the Jetson rail stays up.
Then **repeat the E-stop torque-cut test with the UBEC output disconnected** (nothing driving
`V5_AUX`). "Block A works with firmware dead" (above) is true only while `V5_AUX` is up.
`R13` 10k to `V5_AUX` is Q3's only gate pull-up, so with the UBEC down **expect the bucks to
keep running with the button pressed**. That is the known #430 defect; record the result.
`HARDCUT`'s pull-up (`R9`) is on `V5_AUX` too, so the low-voltage cut is also gone in that state.

## Strain relief + routing notes

- Feetech daisy chain follows the opposite chassis edge from the high-current servo power (reduces capacitive coupling)
- **L2/D456 cable path** (current, post-2026-07-07 head re-architecture +
  AUD-12 — supersedes the old mast-bore/riser-deck-slot route): L2 pigtail
  enters `head.scad`'s crown bore (Ø13×11, x126.5 ±6.5/±5.5). D456's USB-C
  reuses that SAME bore below z106 — rerouted down the column front through
  the face-plate window (AUD-12 fix: a separate channel there would have
  hollowed the head-mount boss's own heat-set inserts). Both then drop
  through `neck_bracket.scad`'s cable slot (18×14, at the deck top) into
  this shoulder's **deck lightening window**, through the shoulder C-box,
  out the Ø12 shoulder flange grommet, into the trunk. Add a TPU
  strain-relief insert (patterns.md §8b pattern) where the bundle
  transitions at the flange grommet.
- Servo wire entry at each leg gets a TPU strain relief (same source)
- **Jetson −Y bundle** (DC barrel + RJ45 + USB-C right-angle adapters,
  backlog #41): sleeve the 3-cable run in spiral wrap (BOM §9) before
  dropping it through the riser's −Y `CASE_SLOT`, seat the TPU
  `case_slot_grommet` (`../cad/chassis/case_slot_grommet.scad`) on the
  slot's cable-bearing edge, then zip-anchor the bundle to the
  grommet's strain-relief tab right where it enters the bay — so plug
  tension at the Jetson ports is relieved by the zip tie + grommet, not
  carried by the port connectors themselves. **No longer blocked** — the
  `riser_bay.scad` CASE_SLOT cut was fixed 2026-07-10 (slot widened
  4.5 → 9 mm at y −49..−40, and `rounded_slot` r dropped 4 → 2.0, which was
  over half the old short span and had blown the cut out past the deck's
  own −Y edge). The chassis gate now clears the grommet against the cradle,
  both clamp bars and the case envelope at 0 pts.
  Still verify at assembly rather than on paper, for a reason the fix does
  not address: **retention is the zip-tie tab, not the edge clip.** The
  gate's 12% edge-clip figure is an inverted proxy (most of the liner's
  volume is cable channel and bay air by design), so it says nothing about
  grip. Check bundle fit and the drop-to-boards run with real cables.
- Battery leads: 18 AWG silicone, exit the pack's REAR face behind the
  trunk end, rise through the shoulder-flange bottom notch (y ±10 →
  z 12 — **TRUNK frame**: x fore-aft, y lateral, z up from trunk floor
  bottom, per `chassis/trunk.scad` / `chassis/riser_bay.scad`) to the MRBF
  block on the floor plate (`../cad/chassis/README.md`), lined with the TPU
  `lead_notch_grommet` (`../cad/chassis/lead_notch_grommet.scad`) — same
  liner role as `case_slot_grommet` above. `docs/improvement-backlog.md`
  AUD-12b labels this same notch "x±10, z −38.1..−26" — that is
  **shoulder-LOCAL frame** (x lateral from centerline, z=0 at the haa axes,
  per `leg_v6/shoulder.scad`'s own frame comment; `lead_notch_grommet.scad`
  states outright it is "built in the SAME shoulder-LOCAL frame as
  shoulder.scad itself, not trunk world coords"). Same physical notch, two
  different frames — not a contradiction, but read each label in its own
  frame.
- ~~E-stop button on chassis side panel~~ **side panel is impossible** —
  the mezzanine owns every wall-depth column (chassis review 2026-07-06).
  E-stop = pod ABOVE the riser deck rear strip, designed with the hood.
- **E-stop 2nd NC contact → logic board J21:** 2-pin, 22 AWG, from the HB2-ES544's *second*
  NC contact block (the first drives SW2 → EN_SW → Q3 → EN_BUCKS, see safety-chain section
  above). J21 pin 1 = signal → Teensy pin 5 (`ESTOP_PIN`, `INPUT_PULLUP`,
  `firmware/teensy/firmware/src/main.cpp:113`); J21 pin 2 = GND. NC-to-GND = LOW idle;
  pressed OR wire-break/unplug = HIGH (fail-safe) — confirmed against the routed net
  (`docs/pre-power-on-validation.md` §1, "Routed F.Cu J21.1→U6.T5") and
  `hardware/pcb-mods/nova_pcb_v6_logic/04_bus_master.kicad_sch`. SW2 kills the bucks in
  hardware; J21 tells `SafetyFSM` in software — wire both, they are not redundant paths to
  the same effect.

## Outstanding wiring decisions

- Exact USB hub config on Jetson — likely only 4 USB-A ports on P3766, may need a powered hub for D456 + Teensy + FE-URT-1 concurrent. Verify on bench.
- ~~Whether to integrate the lighted rocker switch into PCB v6 or panel-mount via flying lead; candidate home = the riser's FRONT-GAP zone (rocker through the side skirt at ~(x 57, z 45))~~ **RESOLVED 2026-08-15 (#368/#377): panel-mount via flying lead, in the FRONT SHOULDER's rear wall** at trunk (x 108, y +1, z 43), long axis VERTICAL, snapped into the 4 mm wall (Blue Sea Contura = Carling V-Series: sprung wings, no screws, 21.08 × 36.83 mm hole, panel band 0.81–6.35 mm). **The riser FRONT-GAP home was impossible** — that column is 10.85 mm wide against a 21.08 mm cutout, and `hardware/cad/chassis/panel_probe.py` found every other proposed face fails too. Wires solder direct to the spades at 90°; heat-shrink past the solder wick and anchor to the shoulder's Ø12 grommets so flex never lands on the joint (this is the ~14 A master feed on a walking machine).
- L2 LiDAR cable routing past the rotating sensor head — needs flex strain relief to survive scans
- **Buck enable pad: `ENA` or `ENB` — UNRESOLVED, and it is the e-stop path.** The reg34c
  module exposes both; no doc records which one `U#`.3 wires to. `EN_BUCKS` has **no
  pull-up on the board**, so the module's internal pull-up is the only thing holding the
  bucks enabled, and the correct pad is the one that **disables when grounded**. Bench
  test before cutting EN wires: VIN ~15 V current-limited, no load → VOUT up with EN
  unattached; ground ENA, then ENB — the pad that kills VOUT goes to `U#`.3. Wrong pad =
  the e-stop does not cut the bucks, silently. See `BUILD_PLAN.md` §5.
- **Buck cable lengths — now derivable, not yet cut.** #366 closed 2026-08-18 (all four
  fit the under-board pocket; reg34c = Pololu #5674, 31.75 × 43.18 × 9.02 mm), so the
  runs can be measured against the chosen placements. Until then do not cut — slack is
  unroutable in the 20 mm gap, short is scrap.
- **`SW2`/`J21` e-stop verify table** (§ as-built above) — specified, not run. Plus the powered
  torque-cut test, both runs, the second with the UBEC output disconnected (#430).
- Servo-bus extension cables (2× waveshare 5264 kits, re-ordered 2026-07-11, arr ~Jul 13):
  **confirm actually in hand and count the 12 in-box cables** before the harness build
  (`master-bom.md` #55 still says "verify routed lengths on receipt").

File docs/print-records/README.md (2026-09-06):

# Print records

One JSON per sliced plate, written by `hardware/cad/slice_plate.py`.

Each record answers **"which revision is this printed part, and what settings
made it?"** — the question that was previously answered from memory, and
answered wrong at least twice (the printed `shoulder` on the bench is a
pre-chamfer revision; the coax was redesigned under #234/#235/#240 after parts
existed).

A record carries:

- `git_head` — the commit the STLs came from
- per part: `stl_sha256_16`, `scad_sha256_16`, orientation, bed contact
- `verified_gcode_keys` — the settings **read back out of the emitted G-code**,
  not the ones requested. See the module docstring in `slice_plate.py` for why
  those are different things.
- `stl_fresh_verified` — whether `check_stl_fresh.py` passed for that plate
- `gcode_sha256_16` — ties the record to one specific G-code file

**Commit a record when the plate is actually printed.** Records from
experiments and dry runs are noise here: a record that says "sliced" reads as
"printed" six months later, which is the same class of mistake this directory
exists to prevent.

## Backfill records (2026-09-05)

The 19 `backfill-<part>.json` files predate `slice_plate.py` recording anything
for these parts — they exist to answer "which revision is this bench part?" for
parts that were already printed before this directory had a writer. They are
**hand-authored**, not written by `slice_plate.py`: built by hashing every STL
export sitting in `~/Downloads` against every git revision of the matching repo
path, then cross-checking that against print-batch.md / STATUS.md / memory for
what was actually printed and when.

Key set (from `backfill-cable_clip.json`): `part`, `printed`, `backfilled`,
`repo_path`, `material`, `settings`, `source`, `status`, `downloads_exports`,
`notes` — a different, smaller set than the `slice_plate.py` schema above, and
filed as `backfill-<part>.json` rather than `{git_head}-{stem}.json`.

`printed` is `true` only where there is cited evidence the part was actually
printed — a ✅ line in `docs/checklists/print-batch.md`, or a STATUS.md /
BUILD_PLAN / memory line saying so. A Downloads export alone is not evidence:
it proves a slice or export happened, not a print (see `backfill-grommet_insert.json`,
corrected 2026-09-05 — the only evidence had been its own Downloads export,
while print-batch.md:82 still showed it unprinted). Everywhere the evidence is
export-only, `printed` is `null`, with a `printed_evidence` field explaining why.

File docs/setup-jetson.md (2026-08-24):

# Jetson Orin Nano Super — Setup

Walked through 2026-05-17 on the actual hardware. Captures the verified procedure for JetPack 6.2.2.

## 1. Flash microSD on Mac

- Download `jp62-r1-orin-nano-sd-card-image.zip` from `developer.nvidia.com/downloads/embedded/L4T/r36_Release_v4.4/jp62-r1-orin-nano-sd-card-image.zip` (NVIDIA Dev account required)
- Unzip
- Flash via Balena Etcher → 128 GB microSD. **Enable "Skip validation"** in settings + run `caffeinate -d` in a terminal to prevent macOS sleep mid-write. Validation hangs if the Mac sleeps.
- ~10 min write

## 2. Pre-boot

- Insert SD card into Jetson SD slot (underside of carrier board)
- Connect: DisplayPort cable to monitor, USB-A keyboard + mouse (the **wired** kind — bluetooth peripherals don't pair until WiFi is up)
- Optional: USB-C cable from Jetson UFP port to Mac (for serial console access — but see Gotcha 2 in [`setup-network.md`](./setup-network.md), it'll hijack the default route later)
- Plug in 12V barrel jack (use included PSU)

## 3. First-boot wizard (text-mode oem-config)

- **APP partition size**: accept default (max — fills the card, ~119 GB)
- **Locale, timezone, keyboard**: as appropriate
- **Hostname**: `nova-jetson`
- **User**: full name "Aiden Fox" → username `aiden`
- **Encrypt home directory**: No
- **Network**: WiFi setup at this stage **WILL FAIL** with cryptic key-exchange error even with correct password. Select "do not configure network at this time" and continue. (See [`setup-network.md`](./setup-network.md) Gotcha 1.)
- **Install Chromium**: Yes (snap install fails without network — that's fine, install later)

Wizard reboots Jetson when done.

## 4. First real boot — fix networking

Login at the text console (or via USB-C serial from Mac with `screen /dev/cu.usbmodem<TAB> 115200`).

Apply the **full WiFi + DNS recovery sequence** documented in [`setup-network.md`](./setup-network.md). Three things to do in order:
1. Connect WiFi via `nmcli` (oem-config WPA bug doesn't affect CLI)
2. Pin DNS in the NM profile + `ignore-auto-dns yes`
3. Write `/etc/resolv.conf` manually + `chattr +i` (NetworkManager on this image doesn't write it)

Verify: `ping -c 2 google.com` works.

## 5. Bump JetPack 6.2.1 → 6.2.2

NVIDIA doesn't ship a 6.2.2 SD image; the upgrade is apt-based but requires bumping the L4T repo from r36.4 to r36.5 first:

```bash
sudo sed -i 's|r36.4|r36.5|g' /etc/apt/sources.list.d/nvidia-l4t-apt-source.list
sudo apt update
sudo apt list --upgradable 2>/dev/null | grep -E "nvidia|l4t" | head    # should show 36.5.0 packages
sudo apt full-upgrade -y
```

Mid-upgrade you'll get one config-file prompt:
> Configuration file `/etc/systemd/nv-oem-config-post.sh` … Deleted by you or by a script.

Hit **Y** (install package maintainer's version). Same answer for any other NVIDIA-shipped config-file prompts unless you've hand-tweaked them.

After upgrade:
```bash
cat /etc/nv_tegra_release   # should show R36 / REVISION 5.0
sudo reboot
```

## 6. Power mode + clocks

After reboot, set MAXN_SUPER (not mode 0 — that's 15W on the Orin Nano Super):

```bash
sudo nvpmodel -p --verbose | grep "POWER_MODEL: ID"
```

Look for `ID=2 NAME=MAXN_SUPER` on the Orin Nano Super Dev Kit (P3766). Set it:

```bash
sudo nvpmodel -m 2
sudo nvpmodel -q       # confirm "MAXN_SUPER"
sudo jetson_clocks     # peg clocks high (with 's', not 'clock')
```

`nvpmodel` persists across reboots; `jetson_clocks` does not. Systemd-enable a oneshot service to peg clocks on every boot:

```bash
sudo tee /etc/systemd/system/jetson_clocks.service > /dev/null <<'EOF'
[Unit]
Description=Set Jetson clocks to max
After=nvpmodel.service

[Service]
Type=oneshot
ExecStart=/usr/bin/jetson_clocks
RemainAfterExit=yes

[Install]
WantedBy=multi-user.target
EOF

sudo systemctl daemon-reload
sudo systemctl enable jetson_clocks.service
sudo systemctl start jetson_clocks.service
systemctl status jetson_clocks.service
```

Expect `Active: active (exited)`. Heredoc gotcha: paste-mangled `tee` blocks can drop trailing lines and break `RemainAfterExit` parsing — confirm with `cat -A /etc/systemd/system/jetson_clocks.service` that lines end with `$` and there are no stray indented lines after `WantedBy=multi-user.target`.

## 7. Bluetooth presence check (resolves Open Decision 2b)

```bash
hciconfig -a           # should show hci0 UP RUNNING + Realtek manufacturer + HCI version
bluetoothctl list
```

On the P3766 dev kit: Realtek controller, BT 5.1, confirmed 2026-05-17.

## 8. SSH key from Mac (kill password prompts)

On Mac:
```bash
ssh-copy-id aiden@10.0.1.135   # use whatever IP the Jetson got
```

Generate the key first if needed: `ssh-keygen -t ed25519 -C "afox@mac"`. After: `ssh aiden@10.0.1.135` no password.

## 9. Optional: mDNS hostname

```bash
sudo apt install -y avahi-daemon
```

Then from Mac: `ssh aiden@nova-jetson.local` — survives IP changes.

## 10. Install jetson-stats (jtop)

```bash
sudo apt install -y python3-pip
sudo -H pip install -U jetson-stats
sudo reboot
```

After reboot: `jtop` runs a TUI showing CPU/GPU/temps/memory/power. Use instead of `htop`.

## 11. Persistence verification (run after any reboot)

Paste this block to confirm everything stuck. Expect 8 green checks:

```bash
echo "=== JetPack ==="; cat /etc/nv_tegra_release | head -1
echo "=== Power ==="; sudo nvpmodel -q
echo "=== jetson_clocks ==="; systemctl is-active jetson_clocks.service
echo "=== CPU freq ==="; cat /sys/devices/system/cpu/cpu0/cpufreq/scaling_max_freq
echo "=== DNS ==="; cat /etc/resolv.conf; lsattr /etc/resolv.conf
echo "=== Route ==="; ip route | grep default
echo "=== Internet ==="; ping -c 2 google.com | tail -2
echo "=== BT ==="; hciconfig hci0 | grep "UP"
```

Expected:
- JetPack: REVISION 5.0
- Power: MAXN_SUPER / id 2
- jetson_clocks: active
- CPU max freq: 1728000 kHz (1.728 GHz — A78AE peak)
- DNS: 8.8.8.8 + 1.1.1.1 with `----i---------e-------` (`i` = immutable flag)
- Route: `default via X.X.X.1 dev wlP1p1s0`
- Internet: <20 ms RTT to google.com
- BT: `UP RUNNING`

Verified 2026-05-17 on actual hardware — all 8 persist across `sudo reboot`.

---

## 12. ROS 2 Humble install (done 2026-05-17)

**Heads up:** the legacy `curl ros.key + sources.list` approach is deprecated. Use the new **ros2-apt-source deb package** (deb822 format, auto-handles key rotation).

```bash
# 1. Locale
sudo apt update
sudo apt install -y locales software-properties-common curl gnupg lsb-release
sudo locale-gen en_US en_US.UTF-8
sudo update-locale LC_ALL=en_US.UTF-8 LANG=en_US.UTF-8
sudo add-apt-repository universe -y

# 2. Install ros2-apt-source (check github.com/ros-infrastructure/ros-apt-source/releases for latest tag)
curl -L -o /tmp/ros2-apt-source.deb https://github.com/ros-infrastructure/ros-apt-source/releases/download/1.2.0/ros2-apt-source_1.2.0.jammy_all.deb
sudo dpkg -i /tmp/ros2-apt-source.deb
sudo apt update

# 3. Install ROS 2 Humble Desktop
sudo apt install -y ros-humble-desktop python3-colcon-common-extensions python3-rosdep python3-argcomplete

# 4. rosdep
sudo rosdep init
rosdep update           # no sudo — writes to ~/.ros

# 5. Auto-source
echo "source /opt/ros/humble/setup.bash" >> ~/.bashrc
source ~/.bashrc

# 6. Sanity
ros2 --help
echo $ROS_DISTRO    # humble
which ros2          # /opt/ros/humble/bin/ros2
```

### Smoke test (talker/listener)

Two SSH sessions:

```bash
# session A
ros2 run demo_nodes_cpp talker

# session B
ros2 run demo_nodes_py listener
```

Listener should print `I heard: [Hello World: N]`. Confirms DDS middleware works end-to-end.

### Paste-gotcha (terminal mangling)

Long curl URLs get newline-broken by some terminal pasters. If `curl: no URL specified!` or `bad/illegal format`, write the command to a file via `nano` (or `echo > install.sh`) then `bash install.sh`. See [`docs/setup-network.md`](./setup-network.md) for the heredoc paste-gotcha pattern.

---

## 13. Intel RealSense D456 install (done 2026-05-18)

Intel ships ARM64 binaries via their apt repo. Stock JetPack 6.2.2 kernel modules expose Color + Depth but **not the IMU streams** — must rebuild 3 in-tree driver modules with RealSense patches.

### Step A — librealsense2 apt install

```bash
sudo apt install -y curl gnupg

# Add Intel repo. Their signing key rotates — fetch current one direct from keyserver.
sudo mkdir -p /etc/apt/keyrings
sudo gpg --no-default-keyring --keyring /etc/apt/keyrings/librealsense.gpg --keyserver keyserver.ubuntu.com --recv-keys FB0B24895113F120
sudo chmod 644 /etc/apt/keyrings/librealsense.gpg

echo "deb [signed-by=/etc/apt/keyrings/librealsense.gpg] https://librealsense.intel.com/Debian/apt-repo $(lsb_release -cs) main" | sudo tee /etc/apt/sources.list.d/librealsense.list

sudo apt update
sudo apt install -y librealsense2-utils librealsense2-dev
```

Verify D456 plugs in clean:
```bash
rs-enumerate-devices | head -20
```

At this point Color + Depth + Infrared streams work. **No IMU yet.**

### Step B — IMU enablement via kernel module patch

Two repos clone to `~/code/`:

```bash
mkdir -p ~/code && cd ~/code
git clone https://github.com/jetsonhacks/jetson-orin-librealsense.git
git clone https://github.com/jetsonhacks/jetson-orin-kernel-builder.git
```

#### B.1 Fetch kernel sources

```bash
cd ~/code/jetson-orin-kernel-builder
./scripts/get_kernel_sources.sh
```

Downloads NVIDIA L4T BSP matching your running kernel (5.15.185-tegra for JP 6.2.2) → `/usr/src/kernel/kernel-jammy-src/`. Copies current `/boot/config-$(uname -r)` as `.config` baseline. ~5-10 min.

#### B.2 Apply RealSense patches

```bash
cd ~/code/jetson-orin-librealsense/build
./patch-for-realsense.sh
```

Applies 2 of 3 patches (the 3rd HID patch is intentionally skipped — already in-tree since L4T 5.15.148).

#### B.3 Enable HID sensor modules in config

```bash
cd ~/code/jetson-orin-kernel-builder
./scripts/edit_config_cli.sh    # opens make menuconfig
```

Use `/` (search) to find + jump to each. Press `M` to toggle to module:
- `HID_SENSOR_HUB` (Device Drivers → HID support → Special HID drivers)
- `HID_SENSOR_ACCEL_3D` (Device Drivers → Industrial I/O support → Accelerometers)
- `HID_SENSOR_GYRO_3D` (Device Drivers → Industrial I/O support → Digital gyroscope sensors)

Save → exit. Confirm:

```bash
grep -E "HID_SENSOR_HUB|HID_SENSOR_ACCEL_3D|HID_SENSOR_GYRO_3D" /usr/src/kernel/kernel-jammy-src/.config
```

All three should be `=m`.

#### B.4 Compile modules

```bash
./scripts/make_kernel_modules.sh
```

~20-30 min on Orin Nano 6-core. Script auto-runs `make modules_install` + `depmod` at the end.

#### B.5 Unplug D456, reboot, plug back in

```bash
sudo reboot
# 90 sec wait
ssh aiden@<ip>
# plug D456 back into USB 3 (blue port)
lsmod | grep hid_sensor
rs-enumerate-devices | grep -A 5 "Motion Module"
```

Expected:
- `lsmod` shows `hid_sensor_hub`, `hid_sensor_accel_3d`, `hid_sensor_gyro_3d`, `hid_sensor_iio_common`, `hid_sensor_trigger`, `uvcvideo`
- `rs-enumerate-devices` Motion Module section shows Accel @ 400/200/100 Hz + Gyro @ 400/200 Hz

### Step C — ROS 2 wrapper

```bash
sudo apt install -y ros-humble-realsense2-camera
ros2 launch realsense2_camera rs_launch.py enable_color:=true enable_depth:=true enable_gyro:=true enable_accel:=true
```

Other session:
```bash
ros2 topic list | grep camera
ros2 topic hz /camera/camera/color/image_raw       # ~30 Hz
ros2 topic hz /camera/camera/depth/image_rect_raw  # ~30 Hz
ros2 topic hz /camera/camera/accel/sample          # ~100 Hz default (settable to 400)
ros2 topic hz /camera/camera/gyro/sample           # ~200 Hz default (settable to 400)
```

For unified IMU topic (single `/camera/camera/imu` at the higher of the two rates), add `unite_imu_method:=2` to the launch line. Most SLAM packages handle separate accel + gyro fine, so the unified topic is optional.

### Verified 2026-05-18

D456 firmware 5.15.0.2 / recommended 5.17.0.10 (firmware update deferred). All streams green at the rates above. Cost: ~$0 (kernel patch path is free, just CPU time).

---

## 14. Teensy firmware build + micro-ROS agent (done 2026-05-19)

Builds + flashes the Teensy 4.1 from the Jetson, and runs the micro-ROS agent that bridges Teensy XRCE-DDS over USB-CDC into ROS 2 Humble. Mac builds are blocked by `micro_ros_platformio` on Python 3.14; Jetson Python 3.10 is the supported build path.

### 14.1 Apt packages (sudo required)

```bash
sudo apt update
sudo apt install -y \
  pipx python3-pip python3-venv python3-vcstool \
  teensy-loader-cli
```

### 14.2 Permissions for Teensy USB

```bash
sudo usermod -a -G dialout aiden
sudo curl -fsSL https://www.pjrc.com/teensy/00-teensy.rules \
  -o /etc/udev/rules.d/00-teensy.rules
sudo udevadm control --reload-rules && sudo udevadm trigger
```

**Log out and back in** (or close + reopen SSH session) for the `dialout` group to take effect. Without it, `pio` cannot open `/dev/ttyACM0` to trigger the USB-CDC reboot into HalfKay before flashing.

### 14.3 PlatformIO via pipx

```bash
python3 -m pipx install platformio
python3 -m pipx ensurepath
```

Open a fresh shell so `~/.local/bin` is on `PATH`. Verify with `which pio`.

**Symlink workaround** — `micro_ros_platformio`'s extra script hard-codes `~/.platformio/penv/bin/activate`. pipx installs to `~/.local/pipx/venvs/platformio/` instead, so symlink the two:

```bash
ln -s ~/.local/pipx/venvs/platformio ~/.platformio/penv
```

### 14.4 Clone repo

```bash
mkdir -p ~/code && cd ~/code
git clone https://github.com/Ace2932/LE_NOVA.git
```

### 14.5 First firmware build

```bash
cd ~/code/LE_NOVA/firmware/teensy/firmware
pio run
```

First build downloads + builds `micro_ros_platformio` dev workspace (~3-4 min on Orin Nano). One transient failure on `rmw_test_fixture` is normal — drop a `COLCON_IGNORE` marker and re-run:

```bash
touch .pio/libdeps/teensy41/micro_ros_platformio/build/dev/src/ament_cmake_ros/rmw_test_fixture/COLCON_IGNORE
pio run
```

Build green ≈ 7 s on incremental, ≈ 3.5 min on cold cache. Output: `.pio/build/teensy41/firmware.{elf,hex}`. Currently sits at ~136 KB flash (1.7% of 7.75 MB).

### 14.6 Build micro_ros_agent from source

```bash
cd ~/ros2_ws/src
git clone -b humble https://github.com/micro-ROS/micro_ros_setup.git
cd ~/ros2_ws
source /opt/ros/humble/setup.bash
rosdep install --from-paths src --ignore-src -y   # ignore unitree_lidar_* rosdep noise
colcon build --packages-select micro_ros_setup
source install/local_setup.bash
ros2 run micro_ros_setup create_agent_ws.sh
ros2 run micro_ros_setup build_agent.sh
source install/local_setup.bash
```

Total ≈ 1.5 min on Orin Nano. Agent binary lands in `~/ros2_ws/install/micro_ros_agent/lib/micro_ros_agent/micro_ros_agent`.

### 14.7 Flash + run workflow

Agent holds `/dev/ttyACM0` exclusively — **kill it before each flash**, restart after:

```bash
# Kill agent (if running)
pkill -f micro_ros_agent

# Flash
cd ~/code/LE_NOVA/firmware/teensy/firmware
pio run -t upload

# Restart agent (detached so it survives SSH disconnect)
setsid bash -c "source /opt/ros/humble/setup.bash && \
  source ~/ros2_ws/install/local_setup.bash && \
  exec ros2 run micro_ros_agent micro_ros_agent serial \
    --dev /dev/ttyACM0 -b 115200 > /tmp/uros_agent.log 2>&1 < /dev/null" \
  </dev/null >/dev/null 2>&1 & disown
```

**Bootstrap order matters:** if the Teensy boots before the agent attaches, the XRCE-DDS handshake never completes (firmware sits in `rclc_support_init` after its 2-second grace delay). To recover, start the agent first then flash — or just re-flash to force a Teensy reboot while the agent is listening.

### 14.8 Smoke test

⚠ **`/joint_commands` is RAW SERVO COUNTS (0..4095), not radians, and NOT
degrees.** `main.cpp`'s `joint_cmd_callback` (firmware/teensy/firmware/src/
main.cpp:568-574) writes `msg.position[i]` straight into
`latched_cmd_position[i]`, and `broadcast_servo_commands()` (main.cpp:
342-414) casts that DIRECTLY to a `uint16_t` and sync-writes it to the bus —
no unit conversion, no calibration. There is also no in-process wrapper on
this topic outside the gait controller (`SafeJointCommandPublisher` +
`_CountsAdapter`, `nova_locomotion/node.py`) — a bare `ros2 topic pub` goes
straight to the firmware. `{position: [0.1, 0, ...]}`, which reads like a
tiny radian nudge, actually commands raw count ~0 on every joint: one end of
travel, on every leg, at once. **Never `ros2 topic pub` to `/joint_commands`
by hand.**

```bash
source /opt/ros/humble/setup.bash
source ~/ros2_ws/install/local_setup.bash
ros2 topic list
# Expect: /heartbeat /loop_max_us /loop_p99_us /joint_states /joint_commands
#         /joint_cmd_rx_count /estop /battery_low /parameter_events /rosout

ros2 topic echo /heartbeat            # 1 Hz Int32, increments
ros2 topic echo /loop_p99_us --once   # 200 Hz loop p99 in microseconds
ros2 topic echo /joint_states --once  # confirm the bridge is alive BEFORE commanding anything
```

**After homing** (calibration artifact present, `nova_calibration`'s homing
run has completed), jog a single joint with `ros2 run nova_ops jog` (#286):
it reads `/joint_states`, converts through the same calibration + limits
table + posture envelope the gait controller uses, and republishes all 12
joints (the other 11 held at their present position, never zeros):

```bash
ros2 run nova_ops jog --joint FL_hfe --delta-deg 5   # +5 deg nudge, clamped + capped at 15 deg
ros2 topic echo /joint_cmd_rx_count --once           # increments by 1 per cmd
```

**Before homing** (no calibration yet — the state this smoke test usually
runs in), `jog` refuses to convert through calibration that doesn't exist.
Use `--raw --delta-deg 0`: with a zero delta the target equals the joint's
own present raw count, so the republished 12-vector is identical to what
`/joint_states` already reported — nothing moves — but `/joint_commands`
still gets a message, which is all `joint_cmd_rx_count` is checking:

```bash
ros2 run nova_ops jog --joint FL_haa --delta-deg 0 --raw
ros2 topic echo /joint_cmd_rx_count --once   # increments by 1 per cmd
```

Baseline 2026-05-19 (stubs only, no executor spin in tick body): `/loop_p99_us` = 5050 (= 50 µs late at 99th pct of 5000 µs nominal period). Real numbers grow once Feetech bus reads + INA226 I²C land.

---

## 15. Unitree L2 lidar + POINT-LIO SLAM (done 2026-05-19)

Brings up the full L2 → ROS 2 → POINT-LIO pipeline on the Jetson. Builds `/unilidar/cloud` + `/unilidar/imu` from the L2 (via a forked `unilidar_sdk2` that fixes the IMU bridge bug), then feeds both into `point_lio_ros2` (dfloreaa Humble fork) which publishes `/cloud_registered` and saves an accumulated PCD on shutdown.

### 15.1 Wiring + IPs

**L2 ↔ Cat 6 ↔ Jetson `enP8p1s0` — DIRECT, no switch** (decision 2026-07-10, swept through the docs 2026-08-14). ~~L2 ↔ Cat 6 ↔ switch ↔ Cat 6 ↔ Jetson~~ — the 5-port switch is bench gear and is not carried on the robot. Corrected here 2026-08-20: the 2026-08-14 sweep updated nine files and missed this one, which is the one you actually follow at the bench. Static IPs via `nmcli connection nova-lan`:
- Jetson `enP8p1s0`: `192.168.1.2/24`
- L2: `192.168.1.62` (factory default for this batch — confirm with `ping 192.168.1.62`)
- L2 UDP cloud + IMU port: `6101` (lidar→Jetson). Jetson local port: `6201`.

### 15.2 IMU bridge fix — point ws at the fork

Upstream `unitreerobotics/unilidar_sdk2` has a bug where `unitree_lidar_ros2` calls `getImuData()` twice in `timer_callback()`, draining the SDK queue before publish. `/unilidar/imu` is advertised but never carries data. Our fork [Ace2932/unilidar_sdk2 branch `fix/imu-bridge-double-call`](https://github.com/Ace2932/unilidar_sdk2/tree/fix/imu-bridge-double-call) removes the redundant call.

```bash
cd ~/ros2_ws/src/unilidar_sdk2
git remote rename origin upstream
git remote add origin https://github.com/Ace2932/unilidar_sdk2.git
git fetch origin
git checkout fix/imu-bridge-double-call
cd ~/ros2_ws
colcon build --packages-select unitree_lidar_ros2
source install/local_setup.bash
```

### 15.3 Launch lidar wrapper + POINT-LIO

Launch the wrapper (publishes `/unilidar/cloud` + `/unilidar/imu`). `setsid` keeps it alive after SSH disconnect; rviz inside the launch file will fail under SSH with no `$DISPLAY` — that's expected, the wrapper itself stays up.

```bash
setsid bash -c "source /opt/ros/humble/setup.bash && \
  source ~/ros2_ws/install/local_setup.bash && \
  exec ros2 launch unitree_lidar_ros2 launch.py \
    > /tmp/unilidar.log 2>&1 < /dev/null" </dev/null >/dev/null 2>&1 & disown
```

Then POINT-LIO:

```bash
setsid bash -c "source /opt/ros/humble/setup.bash && \
  source ~/ros2_ws/install/local_setup.bash && \
  exec ros2 launch point_lio mapping_unilidar_l2.launch.py \
    > /tmp/point_lio.log 2>&1 < /dev/null" </dev/null >/dev/null 2>&1 & disown
```

Watch `/tmp/point_lio.log` — IMU initialization should walk 1 % → 100 % within ~250 ms. If it never reaches 100 %, the IMU topic isn't carrying data — re-check that the wrapper is on the `fix/imu-bridge-double-call` branch.

### 15.4 Verify

```bash
source /opt/ros/humble/setup.bash
source ~/ros2_ws/install/local_setup.bash
ros2 topic hz /unilidar/cloud       # ~12 Hz, 5042 pts/scan
ros2 topic hz /unilidar/imu         # ~250 Hz  ← was empty before the fix
ros2 topic hz /cloud_registered     # ~12 Hz, accumulated map in world frame
ros2 topic hz /aft_mapped_to_init   # ~3.5 kHz, IMU-rate odometry
```

### 15.5 Capture a map

Per `unilidar_l2.yaml`, POINT-LIO writes the accumulated map to `~/ros2_ws/src/point_lio_ros2/PCD/scans.pcd` on a clean shutdown (`SIGINT` from `Ctrl-C` or `kill -INT <pid>`).

Stationary L2 = only the 18-line spoke pattern is visible — walls are sparsely sampled and lost in artefacts. For a real room reconstruction, **carry the L2 through the space** during the run (slow, smooth motion, no fast spins — keeps IMU continuity). Walk through doorways to capture connected rooms. ~30–60 s typically.

### 15.6 Pull PCD off-box

For PCDs in the 50+ MB range, gzip on the Jetson first — typical 60 % size reduction:

```bash
gzip -k -f ~/ros2_ws/src/point_lio_ros2/PCD/scans.pcd
scp aiden@<jetson>:/home/aiden/ros2_ws/src/point_lio_ros2/PCD/scans.pcd.gz ./
```

If wifi to the Jetson is flaky (USB-side carrier or weak wlP1p1s0 signal), upload as a GitHub release asset instead — `gh release create <tag> <file> --repo Ace2932/LE_NOVA` from the Jetson, then `gh release download` from the Mac. Resumable, doesn't break mid-transfer.

---

## 15. Battery-shutdown sudoers rule (required before first battery walk)

`nova_ops battery_shutdown_node` (§10) executes `sudo -n systemctl poweroff` when the
13.0 V comparator latches. `-n` = never prompt, so the node's user needs a passwordless
rule for exactly that one command:

```bash
echo 'aiden ALL=(ALL) NOPASSWD: /usr/bin/systemctl poweroff' | \
    sudo tee /etc/sudoers.d/nova-battery-shutdown
sudo chmod 440 /etc/sudoers.d/nova-battery-shutdown
# verify (should power off — do this at a convenient moment):
sudo -n systemctl poweroff --dry-run 2>/dev/null || echo "RULE NOT WORKING"
```

Scope deliberately limited to `systemctl poweroff` — not blanket NOPASSWD.
Bench-verify the full chain without killing the Jetson:

```bash
ros2 run nova_ops battery_shutdown_node --ros-args -p dry_run:=true
# second terminal:
ros2 topic pub --once /safety_state std_msgs/msg/Int32 '{data: 2}'
# expect FATAL log + /shutdown_imminent + "DRY RUN — would exec" line
```

---

## 16. Watchdogs (system-audit "Jetson watchdog", closed 2026-07-06)

Three layers — each catches what the one below cannot (details:
`ros2_ws/src/nova_ops/nova_ops/watchdog/__init__.py`):

| Layer | Catches | Mechanism |
|---|---|---|
| `Restart=on-failure` | bringup crash | `deploy/nova-bringup.service` |
| `WatchdogSec=15` + `watchdog_node` | ROS stack hang/deadlock | systemd kills + restarts the tree when WATCHDOG=1 stops |
| `RuntimeWatchdogSec=10` | kernel/systemd hang | Tegra SoC HW watchdog reboots the board |

```bash
# 1. bringup service (runs profile=walk at boot, watchdog-armed)
sudo cp ~/nova-proj/deploy/nova-bringup.service /etc/systemd/system/   # adjust repo path
sudo systemctl daemon-reload
sudo systemctl enable nova-bringup     # start on boot; start now only when the bus is wired
# 2. hardware watchdog (kernel hang -> reboot)
sudo sed -i 's/^#\?RuntimeWatchdogSec=.*/RuntimeWatchdogSec=10/' /etc/systemd/system.conf
sudo systemctl daemon-reexec
cat /proc/watchdog 2>/dev/null; ls /dev/watchdog*   # expect /dev/watchdog present
```

Verify the hang-recovery path on the bench (robot on stands / E-stop in):

```bash
systemctl status nova-bringup                     # active, WATCHDOG_USEC visible in env
ros2 topic echo --once /watchdog_fed              # counter > 0 and climbing
# simulate a wedge: SIGSTOP the launch tree, expect systemd restart in ~15s
sudo pkill -STOP -f 'bringup.launch.py'; sleep 20; systemctl status nova-bringup | head -3
```

Notes: the feeder signals *Jetson-stack* health only — Teensy health is the
liveness node's `/system_ok` (deliberately NOT wired into the watchdog: an
unplugged Teensy must not reboot-loop the Jetson). Restart storms are capped
(4 in 2 min, then the unit stays down for the operator). The firmware's own
command-staleness failsafe freezes the robot the moment commands stop, so a
watchdog restart happens on a frozen — not runaway — robot.

---

## Next (separate sessions — Phase 1 plan)

- NVMe install + rootfs migration **(deferred — NAND shortage, see BOM §1; run from 128 GB microSD until prices recover)**
- unilidar_sdk2 + `unitree_lidar_ros2` (done 2026-05-17 — see status log)
- POINT-LIO ROS 2 (dfloreaa fork) + RTAB-Map eval
- Combined D456 + L2 + ROS 2 sensor stream test once switch + Cat6 arrive
- D456 firmware update to 5.17.0.10 via `rs-fw-update` (low priority)

---

> **Status:** updated 2026-05-17 with verified procedure from initial bring-up. JetPack 6.2.2 / L4T 36.5 / MAXN_SUPER / BT confirmed working.

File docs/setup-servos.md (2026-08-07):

# Feetech STS3215 Servo Bus — Setup

ID assignment, bus wiring, and bring-up. v1 scope: **12 active servos** (4 hip + 8 femur/tibia). IDs 13-18 reserved for Phase 4 arm install.

Bus master in v1 is the **Teensy 4.1 (Pattern B)** via SN74LVC125A half-duplex driver (5V-tolerant; NOT the original 74HC125). FE-URT-1 (Pattern A) is the bench / debug fallback selected by `JP_BUS_MASTER` solder bridge on PCB v6.

## Bring-up sequence

1. **ID assignment (pre-PCB or post-PCB), via `scripts/set-servo-ids.py`:**
   `scripts/set-servo-ids.py` speaks raw Feetech protocol directly (no
   Feetech FD, no SCServo SDK) — byte-correct against
   `firmware/teensy/firmware/src/feetech_protocol.h`, unit-tested in
   `scripts/test_set_servo_ids.py`. Install its one dependency first:
   `proj/.venv/bin/pip install -r scripts/requirements.txt`.

   - **Pre-PCB (Week 1-2, recommended):** wire FE-URT-1 directly to one
     servo at a time on the bench (no PCB needed). Do this while waiting
     for PCB v6 to arrive.
   - **Post-PCB (alternative):** if PCB is already in hand, flip
     `JP_BUS_MASTER` to A and use the same FE-URT-1 path through the
     PCB's bus pads.
   Either way: ID setup uses Pattern A's hardware path, **one servo
   connected at a time** — every fresh STS3215 answers to factory ID 1,
   and a second servo on the bus collides with it. The script prints this
   warning itself at the start of every ID-assignment run.

   Walk all 12 IDs in `joint_id_map.yaml` order (FL haa/hfe/kfe = 1-3,
   FR = 4-6, RL = 7-9, RR = 10-12). For each servo: connect it alone,
   confirm it's on factory ID 1, assign, confirm, disconnect, connect the
   next one:
   ```
   # FL_haa (target ID 1) — first servo off the factory line needs no
   # reassignment, but verify + label it:
   proj/.venv/bin/python scripts/set-servo-ids.py --port /dev/ttyUSB0 --ping 1

   # FL_hfe (target ID 2) — connect only this servo, still on factory ID 1:
   proj/.venv/bin/python scripts/set-servo-ids.py --port /dev/ttyUSB0 --old-id 1 --new-id 2
   # label the servo "FL_hfe / ID 2", disconnect, connect the next one

   # FL_kfe (target ID 3):
   proj/.venv/bin/python scripts/set-servo-ids.py --port /dev/ttyUSB0 --old-id 1 --new-id 3

   # FR_haa (target ID 4):
   proj/.venv/bin/python scripts/set-servo-ids.py --port /dev/ttyUSB0 --old-id 1 --new-id 4

   # FR_hfe (target ID 5):
   proj/.venv/bin/python scripts/set-servo-ids.py --port /dev/ttyUSB0 --old-id 1 --new-id 5

   # FR_kfe (target ID 6):
   proj/.venv/bin/python scripts/set-servo-ids.py --port /dev/ttyUSB0 --old-id 1 --new-id 6

   # RL_haa (target ID 7):
   proj/.venv/bin/python scripts/set-servo-ids.py --port /dev/ttyUSB0 --old-id 1 --new-id 7

   # RL_hfe (target ID 8):
   proj/.venv/bin/python scripts/set-servo-ids.py --port /dev/ttyUSB0 --old-id 1 --new-id 8

   # RL_kfe (target ID 9):
   proj/.venv/bin/python scripts/set-servo-ids.py --port /dev/ttyUSB0 --old-id 1 --new-id 9

   # RR_haa (target ID 10):
   proj/.venv/bin/python scripts/set-servo-ids.py --port /dev/ttyUSB0 --old-id 1 --new-id 10

   # RR_hfe (target ID 11):
   proj/.venv/bin/python scripts/set-servo-ids.py --port /dev/ttyUSB0 --old-id 1 --new-id 11

   # RR_kfe (target ID 12):
   proj/.venv/bin/python scripts/set-servo-ids.py --port /dev/ttyUSB0 --old-id 1 --new-id 12
   ```
   If any run prints `ERROR: EEPROM lock write ... FAILED`, that servo's ID
   is live but unpersisted — it can silently revert to the old ID on the
   next power-cycle. Re-run the same `--old-id`/`--new-id` command before
   moving on; do not proceed to the next servo with a failed lock.

   Finally, with all 12 servos daisy-chained on the bus, confirm the whole
   fleet matches `joint_id_map.yaml` in one shot:
   ```
   proj/.venv/bin/python scripts/set-servo-ids.py --port /dev/ttyUSB0 --verify-fleet
   ```
   This prints a table of every expected joint/ID and whether it answered,
   flags any unexpected ID that responds (1-20) but isn't in the map, and
   exits nonzero on any mismatch.

2. **Flip `JP_BUS_MASTER` back to B (default).** Boot Teensy with firmware loaded.
3. **Single-servo bring-up via Teensy:** subscribe to `/joint_states` from Jetson, publish a single `/joint_commands` entry. Verify position tracking + status reads.
4. **Continuity + ping-all:** connect remaining servos, unpowered continuity check, then powered ping-all via Teensy.
5. **Acceptance gate** (per BOM §12 step 3): Teensy loop tick jitter p99 <100 µs + `/joint_commands` arrival rate ≥99% of 100 Hz target + RTT median <5 ms / p99 <20 ms (sanity). The first two are mandatory; RTT is Linux-bounded so don't gate on it.

## Will cover
- ID convention = **PER-LEG SEQUENTIAL** (decided 2026-06-27, `joint_id_map.yaml`, the canonical source `scripts/set-servo-ids.py --verify-fleet` reads): FL haa/hfe/kfe = 1-3, FR = 4-6, RL = 7-9, RR = 10-12. Assign IDs walking the chain leg-by-leg. Hips (haa) = IDs 1,4,7,10 on the 12V rail; hfe/kfe = 7.5V. 13-18 reserved arm.
- Daisy-chain wiring + continuity check (unpowered)
- Voltage rail split: 12V hip (×4) on Pololu D42V110F12; femur/tibia (×8) on Pololu D42V110F7 (7.5V output, within STS3215 7.4V-rated 6-8.4V spec). Arm rail D42V55F7 reserved (Phase 4).
- Per-servo torque/return-delay/temperature limit tuning
- Failure-mode recovery (lost servo, address collision, overheat)
- Teensy firmware verification procedure + gait-loop p99 measurement

> **Status:** the ID-assignment section above is written against
> `scripts/set-servo-ids.py` and is bench-unproven (protocol tested against
> mocks + the firmware's C++ reference, no real STS3215 run yet). Everything
> else below step 1 — per-servo tuning, failure-mode recovery, and the
> Teensy verification procedure — remains a placeholder pending Phase 1
> bring-up.

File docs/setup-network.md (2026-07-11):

# Network Setup — Unitree L2 + Dev Access

Static IPs, Ethernet switch topology, and SSH-over-WiFi for the Jetson.

## Jetson interface naming (JetPack 6.2.x)

JetPack uses systemd predictable names, not `wlan0`/`eth0`:

| Interface | Role |
|---|---|
| `wlP1p1s0` | Built-in WiFi 5 (802.11ac/ab/gn) |
| `enP8p1s0` | Onboard Gigabit Ethernet |
| `l4tbr0` | L4T USB-C gadget bridge (192.168.55.1) — for headless serial console |
| `usb0` / `usb1` | USB net (Mac Internet Sharing path) |
| `can0` | CAN bus (unused for v1) |
| `docker0` | Docker virtual bridge (172.17.0.0/16) |

## Topology decision (2026-07-10): switch is BENCH-ONLY, robot goes L2-DIRECT
On the deployed robot the ONLY wired ethernet device is the L2 (a walking
quadruped can't trail a cable — laptop access is WiFi). So **L2 → straight Cat6
→ Jetson `enP8p1s0`**, point-to-point, no onboard switch (GbE auto-MDIX, no
crossover). Same static IPs. The 5-port switch stays on the BENCH — it only
exists so the dev laptop (.10) + L2 can share the wired LAN while tethered.
Nothing to house/power/crush-protect on the robot. (See harness plan #31.)

## Will cover
- Jetson `enP8p1s0` static IP: 192.168.1.2/24
- Unitree L2 default IP: 192.168.1.62, UDP target port 6101
- 5-port Gigabit unmanaged switch wiring — **bench dev only** (Jetson + L2 + dev laptop)
- Dev laptop static IP: 192.168.1.10
- Verifying L2 UDP packet flow (`tcpdump`, rviz2)
- Simultaneous SSH-over-WiFi while LiDAR streams on Ethernet
- WiFi 5 module (built into P3766) — connecting + signal verification
- Optional: mDNS / Avahi for hostname-based access

## Unitree L2 — confirmed launch params (from unitree_lidar_ros2/launch/launch.py)

After building `unilidar_sdk2` on the Jetson (verified 2026-05-17), the bundled ROS 2 wrapper hardcodes these defaults — match the network plan to these:

| Param | Value | Notes |
|---|---|---|
| `lidar_ip` | `192.168.1.62` | L2 default per Unitree user manual |
| `lidar_port` | `6101` | L2 → Jetson UDP |
| `local_ip` | `192.168.1.2` | Jetson `enP8p1s0` must be set to this |
| `local_port` | `6201` | Jetson receive UDP |
| `cloud_topic` | `/unilidar/cloud` | point cloud out |
| `imu_topic` | `/unilidar/imu` | IMU out (~250 Hz) |
| `cloud_frame` | `unilidar_lidar` | TF frame for URDF |
| `imu_frame` | `unilidar_imu` | TF frame for URDF |
| `cloud_scan_num` | 18 | L2 vertical scan count |
| `range_min` / `range_max` | 0 / 100 m | L2 working range |
| `work_mode` | 0 | UDP mode (1 = serial) |

Launch command (once L2 is on the network + Jetson static IP set):
```bash
ros2 launch unitree_lidar_ros2 launch.py
```

Auto-spawns rviz2 with `view.rviz` config.

### POINT-LIO ROS 2 integration

When wiring POINT-LIO (Phase 2), set its YAML to subscribe:
- `lid_topic: /unilidar/cloud`
- `imu_topic: /unilidar/imu`

### URDF frame mapping

When `nova_description` URDF is written (Phase 1+), link these frames to the L2 mount point on the chassis:
- `unilidar_lidar` — point cloud origin
- `unilidar_imu` — IMU origin (small offset from LiDAR origin per L2 datasheet)

---

## First-boot WiFi / DNS gotchas (Jetson Orin Nano + JetPack 6.2.1)

Hit on 2026-05-17 during initial bring-up. Documenting because every future Jetson re-flash will hit the same things.

### Gotcha 1: oem-config WPA association fails

The text-mode network setup at first-boot has a buggy WPA key exchange. It will report "Failure of key exchange and association" even with correct password. **Don't fight it.** Pick "do not configure network at this time" and finish setup. WiFi works fine from the CLI after boot.

### Gotcha 2: `l4tbr0` USB-C bridge hijacks the default route

If you connected USB-C from Jetson to Mac for serial console access, the Jetson auto-creates `l4tbr0` (192.168.55.0/24) with a default route via 192.168.55.100. This **steals the default route** even when WiFi is up. All outbound packets go to the Mac and die (unless Mac is running Internet Sharing).

**Diagnostic:** `ip route` shows `default via 192.168.55.100 dev l4tbr0`.

**Fix (one of):**
- **Easiest:** unplug the USB-C cable to the Mac. The `l4tbr0` default route disappears, WiFi takes over.
- **Keep USB-C, prefer WiFi by metric:**
  ```bash
  sudo nmcli connection modify "<SSID>" ipv4.route-metric 100
  ```
  Lower metric wins. l4tbr0's default is at metric 32766, WiFi default is at 600 from DHCP — both lose to the L4T bridge's lower path until you override.

### Gotcha 3: NetworkManager doesn't write `/etc/resolv.conf` at all

Editing `/etc/resolv.conf` directly survives until the next `nmcli connection up`. Worse, even after pinning DNS in the NetworkManager profile, **NetworkManager on JetPack 6.2.x does not write the DNS entries to `/etc/resolv.conf` on reboot.** The file ends up empty (size 0), even though `nmcli connection show` reports the correct DNS servers. Result: `Temporary failure in name resolution` after every reboot.

**Step 1 — pin DNS in the NetworkManager profile** (so the connection profile is correct):

```bash
sudo nmcli connection modify "<SSID>" ipv4.dns "8.8.8.8 1.1.1.1"
sudo nmcli connection modify "<SSID>" ipv4.ignore-auto-dns yes
sudo nmcli connection down "<SSID>"
sudo nmcli connection up "<SSID>"
```

`ignore-auto-dns yes` keeps DHCP DNS from re-merging on every `up`.

**Step 2 — write resolv.conf manually + lock immutable** (so NetworkManager can't truncate it):

```bash
sudo chattr -i /etc/resolv.conf 2>/dev/null || true
printf "nameserver 8.8.8.8\nnameserver 1.1.1.1\n" | sudo tee /etc/resolv.conf
sudo chattr +i /etc/resolv.conf
cat /etc/resolv.conf
ping -c 2 google.com
```

`chattr +i` sets the immutable filesystem flag. NetworkManager (or any other agent) cannot modify or truncate the file until you `chattr -i` first. Brute-force durable fix.

**Verify after reboot** — `cat /etc/resolv.conf` should still show the two nameservers. If it ever shows empty, the immutable flag got cleared by an `apt full-upgrade` of `resolvconf`-related packages; just re-apply Step 2.

### Full recovery sequence (copy-paste)

If WiFi association works but `ping google.com` fails:

```bash
# 1. Re-up WiFi to get a fresh default route
sudo nmcli connection up "<SSID>"

# 2. Confirm default route is via wlP1p1s0, not l4tbr0
ip route   # should show: default via 10.0.1.1 dev wlP1p1s0

# 3. Pin DNS + ignore DHCP DNS
sudo nmcli connection modify "<SSID>" ipv4.dns "8.8.8.8 1.1.1.1"
sudo nmcli connection modify "<SSID>" ipv4.ignore-auto-dns yes
sudo nmcli connection modify "<SSID>" ipv4.route-metric 100
sudo nmcli connection down "<SSID>" && sudo nmcli connection up "<SSID>"

# 4. Verify
cat /etc/resolv.conf
ping -c 2 google.com
```

### What was NOT the problem (red herrings tried)

- `iw reg set US` — regdomain. Didn't fix. JetPack 6.2.1 ships with sane defaults.
- WPA3 vs WPA2 on the router. Router was WPA2 already.
- Special characters in password. Password was simple.
- `/etc/resolv.conf` direct edit. Got overwritten on every `nmcli up`.

### After WiFi works — SSH from Mac

Once `ping google.com` works, SSH in from the Mac and drop the serial console:

```bash
# From Mac
ssh aiden@10.0.1.135
```

Replace IP with what `ip addr show wlP1p1s0` reports.

---

> **Status:** updated 2026-05-17 with JetPack 6.2.1 first-boot WiFi recovery sequence. Populate the L2 / static-IP / switch sections when switch + cables arrive (Phase 1).

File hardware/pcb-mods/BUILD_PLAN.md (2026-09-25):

# PCB build plan — v6 power_v2 + logic

Population sequence and the off-board component map, for the two ordered v6
boards. **Not** a validation doc: what to test, and in what order, lives in
`../../docs/pre-power-on-validation.md`. Parts and sourcing live in
`../../docs/order-list.md` and `../../docs/master-bom.md`. This answers "what
do I solder, in what order, and what hangs off the edges".

Inventory below was read out of the two `.kicad_pcb` files on 2026-07-29, not
transcribed from the BOM — where the two disagree, the board files win and the
disagreement is called out.

---

## 1. Inventory

| board | footprints | SMD | THT | mech | DNP |
|---|---|---|---|---|---|
| `nova_pcb_v6_power_v2` | 61 | 24 | 33 | 4 | U5, U12 *(board flags; **U12 IS populated** — §4)* |
| `nova_pcb_v6_logic` | 22 | 10 | 8 | 4 | — |

**power_v2 SMD (24)** — 16× R 0603, 2× C 0603, 3× SOT-23 (Q2 Q3 Q4),
1× SOD-123F (D1), 1× SOIC-8 (U8), 1× **L\_12x12mm\_H8mm (L1)**
**power_v2 THT (33)** — 8× XT30 (J3–J7, J12–J14), 1× XT60 (J1), 5× buck
stations (U1–U5), 5× CP\_Radial D12.5 (C1–C5), 3× CP\_Radial D10 (C6, C8, C9),
4× INA226 breakout (U9–U12), 2× terminal block (SW1, SW2), 1× IDC 2×06 (J20),
1× JST-XH 3 (J8), 1× 1×03 (J2), 1× 1×02 (M1), 1× TO-220 (Q1)

**logic SMD (10)** — 7× R 0603, 1× C 0603, 1× FB 0603 (FB1), 1× SOIC-14 (U7)
**logic THT (8)** — Teensy 4.1 (U6), Arduino Nano (U12), IDC 2×06 (J20),
1×07 (J10), 2× 1×02 (J9, J21), 1×03 jumper (JP1), JST-XH 3 (J11)

### Board size and which side everything is on

Measured from `Edge.Cuts` and each footprint's own layer field:

| board | outline | F.Cu | B.Cu |
|---|---|---|---|
| power_v2 | **112 × 90 mm** | 35 | **26** |
| logic | **84 × 78 mm** | 19 | 3 (R3, R4, R5) |

**power_v2 B.Cu (26)** — C1–C7, L1, Q2–Q4, R2–R9, R11–R16, U8
**power_v2 F.Cu (35)** — C8, C9, C\_gs1, D1, H1–H4, J1–J8, J12–J14, J20, M1,
Q1, R17, R\_gs1, SW1, SW2, U1–U5, U9–U12

Three consequences that are easy to miss:

- **Most of the SMD is on the BOTTOM** (20 of 24: all the 0603 R except R17/R\_gs1,
  C7, U8, L1, Q2–Q4). Only D1, R17, R\_gs1, C\_gs1 are top-side SMD. Stages 1–4
  therefore all work the bottom face; the first flip is at stage 5.
- **The electrolytics are split** — C1–C6 bottom, C8/C9 top. "Electrolytics last"
  applies to both faces.
- **Top-side THT is soldered from the bottom face**, which by then carries 20 SMD
  parts including L1 at 8 mm tall. This is a second, independent reason the
  bottom-side electrolytics (C1–C6, 12.5 mm cans) must wait: they would block
  iron access to the very pads at stage 8.

### Two corrections to `master-bom.md` (applied there 2026-07-29)

Its reflow-skip line read *"21 SMD parts all 0603/SOT-23/SOIC, hand-solder"*.

1. **The count is 34**, not 21 (24 + 10 across both boards).
2. **They are not all 0603/SOT-23/SOIC.** L1 is `L_12x12mm_H8mm` — a 12×12 mm
   power inductor on the L2 rail (`V12_L2_RAW` → `V12_L2`), and there are two
   SOIC (U8 SOIC-8, U7 SOIC-14).

The *conclusion* still holds — hand-solder, no stencil, no hotplate. But L1 is
the hardest joint on either board, not a 0603, and the plan below sequences it
accordingly.

---

## 2. Tooling — the one real gap

Owned (`master-bom.md`): Pinecil V2, flux, wick, sucker, and — **confirmed 2026-08-01** —
solder: **Sn63Pb37, 1 mm, 1.8 % flux core**. Leaded, as §2a recommends, so **the leaded column
in §2a is the live one and nothing shifts +30 °C**. The stage-1 blocker is closed. ⚠️ The
diameter is **1 mm, not the 0.6–0.8 mm** originally specced — see §2a for what that changes
(technique at stages 1/3, not a re-order).

`pre-power-on-validation.md` §1d records the trap: `VBAT_PROTECTED` (PWR.Cu)
and `GND` (GND.Cu) are **solid pad-connected planes**, deliberately — the
high-current pads were thermal-relief throats good for only ~6 A and would
have overheated. The cost is that those pads now **wick heat straight into the
plane**, and that note ends: *"a bare 60–88 W Pinecil will struggle on the big
ones."*

**The only iron on the BOM is exactly the iron that note says will struggle.**

Two things govern whether it actually struggles, and only one of them is the tip.

- [x] **Tip mass — DONE, kit owned** (confirmed 2026-07-29). LUMINZENLUX
      TS100/Pinecil V2 6-pack: **TS-C4** ≈4 mm bevel, **TS-D24** ≈2.4 mm chisel,
      TS-K knife, TS-ILS, TS-J02, plus a **threaded insert adapter**. TS-C4 is
      the tip for the plane-tied pads. The insert adapter also replaces the
      ad-hoc M3 heat-set tip in `../../docs/checklists/print-batch.md`, so the
      same kit covers PCB and printed-part work. Logged in
      `../../docs/master-bom.md`, which previously listed only "Pinecil V2
      iron" — which is why this was an open question at all.

  **Tip per stage** (stages in §3):

  | tip | use | stages |
  |---|---|---|
  | TS-ILS (fine long conical) | 0603 R/C, SOT-23, SOD-123 | 1–2, 5 |
  | TS-K (knife) | SOIC drag-solder, bridge wicking | 3 |
  | TS-C4 (≈4 mm bevel) | **every plane-tied / high-current pad** — L1, SW1.2, Q1.3, U1.4, XT60/XT30, buck stations | 4, 7, 8 |
  | TS-D24 (≈2.4 mm chisel) | general THT — headers, JST, terminal blocks, electrolytics | 6, 9 |
  | TS-J02 (bent fine) | tight rework, no straight-on access | any |
  | threaded insert adapter | M3 heat-sets in printed parts (not PCB) | — |
- [x] **Supply voltage — DONE, two adequate supplies owned.** The half that
      gets forgotten: the element is resistive, so power goes as **V²**. What
      matters is voltage, *not* USB vs barrel — a 65 W PD brick is fine, a
      9–15 V one is not, and no tip compensates for the difference.
      - **Anker Nano II 65 W GaN** (owned): negotiates 20 V / 3.25 A = 65 W,
        inside the 60–88 W band the note above assumes. Fine for every stage
        **except** the plane-tied joints at 4, 7 and 8 — use the bench supply
        for those. Needs a PD C-to-C cable rated ≥3.25 A, not a charge-only lead.
      - **Kungber 30 V/10 A** (owned): **prefer this for the plane-tied joints at stages 4, 7 and 8.**
        **24.0 V** into the DC 5525 barrel is 24²/20² ≈ **1.44×** the 20 V PD power, free.
        That headroom is exactly what the 14 A plane pads want. ⚠️ **24 V is the Pinecil V2's
        DC ceiling** (barrel 12–24 V, 24 V/5 A) and this is a 30 V supply — dial it down and
        confirm on the display before plugging in; current limit ≥4 A. Details in §2a.
- [x] **Preheat — SOLVED. Test run 2026-08-01, PASSED, do not buy.** No
      purpose-built preheater is owned and none is needed. `U1.4` (10 A) wet in
      **~2 s with solder through to the far face**; `Q1.3` (**14 A GND inject** —
      the worst THT pad on the board) went easy and came out **shiny on both
      faces**, i.e. the barrel wicked. Setup: **TS-C4, Kungber 24.0 V (~88 W),
      tip 400 °C, Sn63Pb37 1 mm** — heat the pad ~2 s, then feed into the tip/pad
      junction. Full result in §2a. The conditional buy is **closed, not deferred**.
      **Consequence:** if the 14 A GND inject goes in seconds, every XT30/XT60 and
      `SW1.2` is the same problem or easier — the high-current THT is no longer the
      risk item in this plan.
      ⚠️ **The one joint the test did NOT model is `L1` (stage 4)**: SMD, plane-tied
      on *both* sides, so there is no barrel and "solder on the far face" does not
      apply — it is a fillet against a plane sinking heat from underneath as well as
      laterally. If it fights, the answer is the **420 °C boost held a few seconds,
      not a purchase**. The P1S bed (§2a) remains available for stage 4 and is free.
      ⚠️ The Etekcity IR gun **cannot** stand in as the measurement here: 16:1 optics
      (22.6 mm spot at its recommended distance) and a matte-surface emissivity
      assumption make it useless on a 2–3 mm shiny pad. It reads *bulk board*
      temperature only. §2a explains, and uses solder phase-change instead.

  *Kept for the record — the spec that would have applied had it failed.*
  **It would have had to be IR, not a contact hotplate.** Both faces of
  power_v2 are populated (§1), so a flat plate can only heat a face that is
  still bare:

  | stage | needs preheat? | contact plate? |
  |---|---|---|
  | 1–4 (bottom SMD incl. L1) | L1 yes | ✅ top face still bare — lay it top-down |
  | 7–8 (SW1.2, Q1.3, U1.4, XT30s) | yes, most of them | ❌ bottom populated **and** top carries tall connectors — it will not lie flat either way |

  A contact plate therefore covers L1 and **not** the three 14 A pads, which are
  the joints the warning is actually about. Candidate: **YIHUA 853A** IR station,
  ~$85, 130×130 mm heated area (covers 112×90 with margin), 50–350 °C PID.
  MHP30 (30×30) and MHP50 (50×50) are far too small for this board despite
  being the usual hobby recommendations.

  **Hot air is not a substitute.** It is localised and fights the same plane
  conduction that makes these pads hard; preheat works by removing the gradient,
  which needs bulk heating. A hot-air station (e.g. YIHUA 8786D, ~$70) is still
  worth owning for **stage 3** SOIC rework and for harness heatshrink — just do
  not buy it expecting the plane pads to improve.

### Pads that need the fat tip + preheat

| pad | net | current |
|---|---|---|
| SW1.2 | `VBAT_PROTECTED` | 14 A inject |
| Q1.3 | `GND` | 14 A GND inject |
| U1.4 | `V7V5_LEG` | 10 A leg VOUT |
| J1 (XT60) | `VBAT` / `BATT_NEG` | pack feed |
| U2–U4.1/.2/.4 | `VBAT_PROTECTED` / `GND` / rail | buck VIN/VOUT |
| L1 | `V12_L2_RAW` / `V12_L2` | SMD, 12×12, plane-tied |

---

## 2a. Iron temperature and Pinecil V2 setup

The tip table above says *which* tip. This says *how hot*, and how to actually get
the iron there. Verified against Pine64's Pinecil docs and the IronOS settings
reference on 2026-07-31 — but IronOS menu wording shifts between releases, so
trust the on-device help text over this table if they disagree.

### The alloy — CONFIRMED 2026-08-01: Sn63Pb37, 1 mm, 1.8 % flux core

Leaded, which is what this section recommended. **The leaded column below is the
live one** — the bracketed lead-free setpoints do not apply and nothing in this
document shifts +30 °C.

Why it was the right call anyway:

- It melts at **183 °C** vs SAC305's **217–220 °C**, so every joint happens
  ~35 °C cooler — and the whole difficulty here is getting heat *into* a plane.
- The **logic board is HASL-lead** (§ the JLC order spec), so its pads are already
  tin-lead. Lead-free wire onto lead-plated pads makes a mixed alloy — it works,
  but there is no reason to take it.
- The power board is ENIG, which is happy with either.

**Eutectic, so the inspection criterion is simple: a correct joint is SHINY.**
Sn63Pb37 has **no plastic range** — it goes solid at 183 °C with no mushy interval
to freeze badly in. Dull grey or grainy *after the flux is cleaned off* therefore
means the joint moved while freezing or was heat-starved. It is a defect signature,
not a finish preference — and it is the **opposite** of SAC305, where a correct
joint is legitimately dull. Do not carry that habit over.

⚠️ **"After the flux is cleaned off" is a precondition, not a throwaway clause.**
The owned flux is *no-clean*, whose cured residue is glossy — so an uncleaned board
does not withhold the verdict, it **forges a passing one**. See the next subsection;
it is the reason there is now an explicit clean-and-inspect step at all.

⚠️ **The diameter is 1 mm, not the 0.6–0.8 mm `master-bom.md` originally specced**,
and it cuts both ways along the stage split already in §3. 1 mm carries **~2.8× the
solder per mm of feed**, which:

- **helps** at stages **4/7/8** — the plane-tied pads, where the entire difficulty
  is delivering mass and heat before dwell cooks the laminate;
- **hinders** at stages **1/3** — 0603 pads are ~0.8 mm, so feeding 1 mm wire
  over-delivers and bridges.

Fix is technique, not a second spool: **tin the tip and place** on the 0603s rather
than feeding wire, and keep U7/U8 to flux + drag/wick where the wire barely touches.

**1.8 % rosin core is standard, but it flashes off fast at 380–400 °C.** The
separate flux below is mandatory for stages 4/7/8 and the U7/U8 drag — core flux
alone is gone before the joint wets at those temperatures, and that reads as "the
plane is winning" when it is actually flux starvation.

### The flux — CONFIRMED 2026-08-01: BEEYUIHF, lead-free / no-clean / non-conductive

Label claims, not a datasheet; form, volume and IPC classification are unrecorded.

**"Lead-free" does not mean incompatible with Sn63Pb37.** It describes the *flux* —
formulated to stay active up to SAC305's 217–220 °C. Leaded joints happen ~35 °C
cooler, so the flux is over-specified for this build, never under-. Activation is
~150–200 °C and every stage here runs a 320–400 °C tip, so it is fully spent inside
the joint. No purchase, no substitution.

**Stage 1 needs it too — and the reason is technique, not temperature.** The rule
above (mandatory at 4/7/8) is about flux *burning off*. Stage 1 loses it a different
way: §2a prescribes **tin the tip and place** on the 0603s because 1 mm wire
over-delivers on a 0.8 mm pad. But core flux lives *inside the wire* and deploys
where the wire melts — and tip-carry melts it **on the tip**, so the flux flashes off
up there and what reaches the pad is bare solder carrying nothing. The technique that
solves the diameter problem creates a flux-starvation problem. Per 0603:

1. Dab flux on both pads.
2. Tack one end with the tip-carried blob, ~1 s. Part is now anchored, tweezers free.
3. Second end: **feed fresh wire** into the joint — core flux fires right there. This
   is the cleaner of the two joints.
4. Reflow end 1 with a touch of fresh wire so both ends match.

**"Non-conductive + no-clean" closes the R4/R6 leakage question.** `R4` 11.3k and
`R6` 12.1k are the trip-point divider, so residue leakage across a leg would move a
protection threshold rather than fail loudly. Run the number: a 1 % shift needs
~1.1 MΩ in parallel with the 11.3k leg. Cured no-clean residue sits orders of
magnitude above that. Not a concern.

#### ⚠️ What it does open: the residue forges a PASS

Cured no-clean residue is **glossy**. The correctness criterion for eutectic solder
is **shiny**. So a film of clear residue over a dull, grainy, heat-starved joint
**reads as a good joint**.

This is the failure mode worth naming, because it is not "you cannot tell" — it is a
confident wrong answer, biased in the PASS direction, on the one criterion this
document relies on. It defeats exactly the defect (moved while freezing, or
heat-starved) that the shiny rule exists to catch.

**So the verdict is only available after cleaning. Per stage, before moving on:**

Use the **aerosol flux remover** (MG Chemicals 4140, ordered 2026-08-02), not plain IPA.
The chemistry matters here: our flux is **no-clean**, the residue class IPA handles worst,
and IPA only *partially* dissolves it — the resin redeposits as a **white haze**. That is
the mirror of the uncleaned failure above: uncleaned reads glossy → **false PASS**;
half-dissolved reads hazy → **false FAIL**. Plain IPA, used imperfectly, puts errors on
both sides of the one criterion this document relies on. 4140 is rated for no-clean and
states *"safe on plastic components"*, which is what makes it usable at stage 10 alongside
the Teensy/Nano/INA modules and the OLED window.

1. Board **COOL** — it is a flammable aerosol and you have just been at 320–400 °C.
2. Stand the board **angled over paper towel** so runoff carries residue OFF the edge.
   This is the whole mechanical advantage over wiping: it *flushes* rather than
   redistributes.
3. Short bursts through the **extension straw**, working top-down.
4. Brush while wet (acid brush or an old toothbrush).
5. **Final flush with no brushing** — that pass carries the loosened residue away
   instead of spreading it. Do not finish on the brush stroke.
6. Let it flash off and come back to **room temperature** before judging. The propellant
   chills the board, and in coastal air a chilled board fogs — condensation on a good
   joint reads as dull.
7. *Now* judge shiny. Rework anything dull or grainy before the next stage — not at the
   end, when the board no longer sits flat and the pad is behind a tall part.

99 % IPA is still worth having and is **not** a substitute here — it is for general prep,
tool wiping and the printer's PEI plate. If you ever have to fall back to it on a board,
the old rule applies: flood → brush → **blot lint-free** → repeat, because with IPA the
wicking step is the only thing stopping the smear.

Second-order, and specific to this combination: a lead-free-rated flux run at leaded
temps leaves **peripheral** residue — squeezed outside the joint, never hotter than
60–100 °C — less fully spent than the flux inside it. No-clean is only inert once
heat-activated. On a machine that vibrates and collects dust, that is the residue
worth removing even though the joints themselves are fine.

### Temperature by stage

Leaded first, lead-free in brackets. These are *tip setpoints*, not pad temperatures.

| stages | parts | tip | setpoint |
|---|---|---|---|
| 1, 2, 5 | 0603, SOT-23, SOD-123F | TS-ILS | **320 °C** (350) |
| **5 — `BATT_NEG` ends only** | **`D1`.2 · `R_gs1`.2 · `C_gs1`.2** | **TS-D24** | **380 °C** |
| 3 | U8 SOIC-8, U7 SOIC-14 — drag/wick | TS-K | **330 °C** (355) |
| **4, 7, 8** | **L1, SW1.2, Q1.3, U1.4, XT30/XT60, buck stations** | **TS-C4** | **380–400 °C** (400) |
| 6 — signal pins only | headers, JST, IDC | TS-D24 | **330 °C** (355) |
| **6 — GND + rail pins (power board = MOST of the stage)** | **`J2` all 3 · `M1` both · `J8` all 3 · `J20` GND×5 + V5_AUX×2** | **TS-C4** | **380–400 °C** |
| 9 | electrolytics — **≤3 s per lead** | TS-D24 | **340 °C** (360) |
| 10 | module headers / sockets | TS-D24 | **330 °C** (355) |

🔴 **STAGE 5 IS NOT A UNIFORM STAGE — three of its eight pads are heavy copper.** Found at
the bench 2026-08-08: solder would not wet one pad of a stage-5 part. Read out of the board
file, the widest trace touching each stage-5 pad:

| pad | net | widest trace |
|---|---|---|
| **`D1`.2** | `BATT_NEG` | **3.00 mm** |
| **`R_gs1`.2** | `BATT_NEG` | **3.00 mm** |
| **`C_gs1`.2** | `BATT_NEG` | sits on the **F.Cu `BATT_NEG` pour** |
| `D1`.1 · `R_gs1`.1 · `C_gs1`.1 · `R17`.1 · `R17`.2 | — | 0.20 mm |

Every stage-5 part therefore has **one ordinary end and one heavy end** — 15× the copper,
running back to `J1`'s 36 mm² XT60 pad, `Q1`'s tab and the pour. Note it is the **trace**,
not the pour touching the pad: the pour stops at y 67.5 while `D1`.2/`R_gs1`.2 sit at
y 70–72. `C_gs1`.2 at y 67.75 is on the pour edge and is the worst of the three.

**This stage was filed under "small parts" because most of it is small** — the same mistake
that put `L1` among the ordinary 0603s in the retired checklist, and it contradicts §2a's own
rule that **TS-ILS never goes on a plane-tied pad**. Fix: **TS-D24 at 380 °C for the three
`BATT_NEG` ends**, TS-ILS 320 °C for the other five. TS-C4 also works but is clumsy on 0603.
Separate flux on the heavy end, tin the tip first, and land the flat so it touches pad *and*
trace. **Tack the 0.20 mm end first**, then change tips — the part is then located and cannot
shift while you work the heavy end.

⚠️ Do **not** answer a non-wetting heavy pad by pressing a fine tip harder for longer. A
low-mass tip sags against 3 mm of copper, and the dwell is what lifts pads — see the
hotter-is-gentler note below.

**GENERALISATION: a per-stage tip/temperature spec is wrong the moment one pad in that stage
sits on different copper. Check trace width and pour membership PER PAD, not per stage.**

### 🔴 STAGE 6 IS THE SAME TRAP, LARGER — 19 of the power board's 20 pads are heavy

Checked *ahead* of the iron 2026-08-08 by applying the rule above, rather than discovered by
a pad that would not wet:

| connector | heavy pads | on what |
|---|---|---|
| `J2` | **3 of 3** | `VBAT_PROTECTED` (the whole-board **In2.Cu** plane) · GND · `V5_AUX` 1.50 mm |
| `M1` | **2 of 2** | `VBAT_PROTECTED` plane · GND |
| `J8` | **3 of 3** | GND · `V7V5_LEG` **2.00 mm** (servo rail) · `BUS_SERVO` |
| `J20` | **11 of 12** | GND ×5 · `V5_AUX` ×2 at 1.50 mm · rest in small local pours |

So stage 6 on power_v2 is not "headers and JSTs" — it is **mostly plane-tied through-hole**.
**TS-C4 at 380–400 °C on every GND and rail pin**; keep TS-D24 330 °C for the signal pins
(`SDA` / `SCL` / `BATT_LOW` / `+3V3` / `BUS_SERVO`), which sit in small local pours and
behave normally.

**No new bench test is needed to justify this** — §7's preheat trial already passed at exactly
this setup on `Q1`.3, the 14 A GND inject and the worst THT pad on the board: wetted in
seconds, shiny on both faces. Every pad here is easier than that one.

**LOGIC board stage 6 is much lighter.** Only the GND / `V5_AUX` pins on `J9`, `J10`, `J11`,
`J20` are pour-tied. `JP1` and `J21` are entirely ordinary and `J10`'s five SPI pins are
0.25 mm, so TS-D24 330 °C is correct there.

### 📋 PER-COMPONENT TIP PLAN — every remaining pad, both boards (2026-08-08)

Generated from the two `.kicad_pcb` files: for each pad, the widest trace touching it and the
area of any same-net pour containing it. **HEAVY** = in a pour > 300 mm² or on a trace
≥ 1.0 mm. This replaces the per-stage rows above wherever the two disagree.

**TS-C4 380–400 °C on every HEAVY pad. TS-D24 330 °C on the rest.**

#### 🔴 The electrolytics are the one that matters — and the instinct is backwards

**`C1`–`C6` have BOTH pads HEAVY** (`V7V5_LEG` 7258 mm² / `V12_HIP` / `V12_L2` on one side,
the 15183 mm² GND pour on the other) — and they are also the **heat-sensitive ≤ 3 s/lead**
parts. Those two facts fight, and the stage-9 row above (TS-D24 340 °C) loses: a D24 at
340 °C will **not** wet a 15000 mm² pour inside 3 s, so you end up dwelling — which is
precisely what cooks an electrolytic.

**Use TS-C4 at 400 °C and get out in ~2 s.** Hotter is *gentler* here, same as §2a's
plane-tied argument: 400 °C for 2 s puts far less energy into the can than 340 °C for 12 s
spent waiting for a joint that never quite flows. Do not lower the temperature because the
part is heat-sensitive — that is the move that damages it.

`C8`/`C9` are easier: GND pad HEAVY, `VBAT_PROTECTED` pad light.

#### Power board

| stage | part | HEAVY pads (TS-C4 400 °C) | rest (TS-D24 330 °C) |
|---|---|---|---|
| 6 | `J2` | **all 3** — VBAT_PROTECTED plane 13782, GND 15183, V5_AUX 1.5 mm | — |

⚠️ **`J2` takes FOUR wires into THREE pins.** The SoloGood UBEC has separate input and
output grounds: input red → `J2`.1, input black → `J2`.2, output red → `J2`.3, output black
→ `J2`.2 **as well**. Splice the two blacks into one pigtail before the header — the ~20 AWG
input lead will not share a 1 mm hole with the servo lead. See `docs/order-list.md`.

| 6 | `M1` | **both** | — |
| 6 | `J8` | 1 (GND), 2 (`V7V5_LEG` **2.0 mm**) | 3 |
| 6 | `J20` | 1, 2 (V5_AUX 1.5 mm), **3, 4, 10, 11, 12** (GND) | 5–9 |
| 7 | `SW1` | **both** — pad 1 `VBAT` 3.0 mm, pad 2 the 13782 plane | — |
| 7 | `SW2` | 1 (GND) | 2 (`EN_SW`) |
| 8 | `J1` XT60 | **both** — 3.0 mm each | — |
| 8 | `J3` `J4` `J5` `J6` | **both each** — GND pour + `V7V5_LEG` 7258 | — |
| 8 | `J7` `J12` `J13` `J14` | **both each** | — |
| 8 | `U1` | 1, 2 (×3 GND), 4 | 3 (`EN_BUCKS`) |
| 8 | `U2` | 1, 2 (×3) | 3, 4 |
| 8 | `U3` | 2 (×3), 4 | 1, 3 |
| 8 | `U4` | 4 only | 1, 2, 3 |
| 8 | `Q1` | **3** (the 14 A GND inject) | 1, 2 |
| **9** | **`C1`–`C6`** | **BOTH pads — see the box above, C4 400 °C, ≤ 3 s** | — |
| 9 | `C8` `C9` | 2 (GND) | 1 |
| 10 | `U9`–`U12` INA | 7 (GND) | 4, 5, 6 |

⚠️ `J20` pad 3 measures outside the pour outline while pads 4/10/11/12 sit inside it. Treat
**all five GND pins as heavy** — the difference is a polygon edge, not a thermal one.

#### Logic board

| stage | part | HEAVY pads (TS-C4 400 °C) | rest (TS-D24 330 °C) |
|---|---|---|---|
| 6 | `J9` | 1 (GND 8490) | 2 |
| 6 | `J10` | 1 (GND), 2 (`V5_AUX` 7969) | 3–7 (SPI, all 0.25 mm) |
| 6 | `J11` | 1 (`V5_AUX`), 2 (GND) | 3 |
| 6 | `J20` | 1, 3, 4, 10, 11, 12 | 2, 5–9 |
| 6 | `J21` · `JP1` | **none** | all |
| 10 | `U6` Teensy | **none** — all 12 pads light | all |
| 10 | `U12` Nano | 4, 29 (GND) | the other 28 |

`U6` being entirely light is worth knowing: the Teensy socket is 12 ordinary pads and needs
no tip change at all.

**Do not set a WORKING temperature above 400 °C.** Past that the flux flashes off
before it can wet, tip plating degrades quickly, and you get *worse* joints, not
faster ones. **The 420 °C boost below is the deliberate exception** — it is held
for a few seconds on one stubborn pad, not dialled in and left there. Keep the
distinction: 400 °C is the ceiling you *work* at, 420 °C is a momentary reserve.

**The counter-intuitive bit, and the one that matters for stages 4/7/8:** a hotter
tip is *gentler* than a cooler one on these pads. Damage is time-at-temperature at
the laminate, not tip setpoint. 400 °C for 3 s puts far less heat into the board
than 340 °C for 15 s spent waiting for a joint that never quite flows. §7 already
names this failure — *"sitting on a pad waiting is what lifts pads and cooks
laminate"* — and the fix is more tip temperature and less dwell, not less of both.

**Technique for the plane-tied pads** (this is worth as much as the wattage):
tin the tip first so there is a molten thermal bridge, land the **largest flat
face of the tip** against the pad for maximum contact area, and feed solder into
the tip/pad junction — not onto the tip. Contact area is the actual bottleneck
once you have 88 W behind you.

> ⚠️ `master-bom.md` and §2 both describe TS-C4 as a *"≈4 mm bevel"*. In the usual
> TS100 naming a `C`-prefix tip is a **chisel** and `BC` is the bevel/hoof, so the
> kit's actual geometry is worth one look before stage 4. It does not change which
> tip to use — TS-C4 is the fattest one either way — only how you present it:
> chisel → flat face down, bevel → the elliptical face down. Maximise contact.

### Supply — set the Kungber to 24.0 V, not higher

Pinecil **V2's DC5525 barrel is rated 12–24 V, 24 V–5 A maximum**, and it reaches
24 V without any PCB modification. Its published range is **18–88 W**, and 88 W is
**24 V at 3.66 A**.

> ⚠️ The Kungber is a **30 V/10 A** supply. **24 V is the Pinecil V2's ceiling, not
> a suggestion** — dial it to 24.0 V and confirm on the display before plugging the
> iron in. Set the current limit to **≥4 A** so the supply does not fold back into
> CC mode mid-joint, which would silently cost you the power you set all this up for.

| supply | gives | use for |
|---|---|---|
| Kungber bench, **24.0 V** into DC5525 | up to 88 W | **stages 4, 7, 8** (L1 + the 14 A pads) |
| Anker Nano II 65 W GaN, USB-C PD | 20 V / 3.25 A = 65 W | every other stage |

The Anker needs a PD C-to-C cable rated ≥3.25 A — a charge-only lead will
quietly negotiate something lower. (V2 also *unofficially* does PD 3.1 EPR at
28 V/140 W with a certified EPR cable; you do not need it, and 24 V from the
bench supply is the known-good path.)

### IronOS settings — what to change

Navigation, with the tip fitted, from the main screen:

- **Button nearest the TIP** → enter soldering mode.
- **Button nearest the USB end** → enter the settings menu.
- **Hold the tip-side button while soldering** → boost.
- **Hold the tip-side button on the main screen** → temperature adjust.

| menu | setting | set to | why |
|---|---|---|---|
| Power | **Power source** | **DC** | On the bench supply. This sets a 10 V cutoff instead of a per-cell battery cutoff — leave it on a cell count and the iron may cut out or clamp power. |
| Power | **Power limit** | **88 W** on the Kungber | The average wattage the iron targets. On USB-PD it is automatically the *lower* of this and the supply's advertised wattage, so 88 W is safe to leave set — the Anker will still cap itself at 65 W. |
| Power | **PD Mode** / **PD timeout** | leave default | Only touch these if a charger misbehaves; PD timeout exists for QC-charger compatibility. |
| Soldering | **Boost temp** | **420 °C** | Your reserve for a 14 A pad that will not wet. Held, not latched — a few seconds, then back off. |
| Soldering | **Temp change long** | 25 °C (optional) | You will be moving between 320 and 400 °C repeatedly across stages; the default 10 °C step makes that tedious. |

### §7's preheat test — RUN 2026-08-01, **PASSED**. Do not buy a preheater.

**Result: both pads wet and filled in ~3–4 s, shiny on both faces.**

| pad | rating | result |
|---|---|---|
| `U1.4` | 10 A — least severe | ✅ ~2 s to wet, solder through to the far face |
| `Q1.3` | **14 A GND inject** — tied straight into the ground plane, the worst THT pad on the board | ✅ easy, **shiny both sides** |

**Why "shiny both sides" is the whole verdict in one observation:** shiny = eutectic
Sn63Pb37 froze undisturbed and not heat-starved; on *both* faces = the solder wicked
the barrel. A plane-starved pad gives the exact opposite — a blob on the iron side
and nothing through the hole.

Setup that achieved it: **TS-C4, Kungber 24.0 V (~88 W), tip 400 °C, Sn63Pb37 1 mm.**
Heat the pad ~2 s, then feed solder into the tip/pad junction.

⚠️ **`L1` (stage 4) is the one joint this did not model** — SMD, plane-tied on *both*
sides, no barrel, so the far-face criterion does not apply. If it fights, use the
420 °C boost, not a purchase.

*The rest of this section is the original criterion, kept because the measurement
reasoning still governs any joint that has to be re-run.* Run as: **TS-C4, Kungber at
24.0 V, tip 400 °C, solder placed ON THE PAD** (not melted off the tip). Start on
`U1.4` (10 A, least severe of the three), then `Q1.3` or `SW1.2` (14 A).

> ⚠️ **Correction to the first version of this section.** It said to fail the test
> if the Etekcity IR gun read the pad below ~185 °C. **Do not point the IR gun at a
> pad** — that criterion was unsound and would have produced false failures:
> - **Spot size.** The Lasergrip 800 is **16:1**, and at its own recommended 36 cm
>   working distance the spot is **22.6 mm across**. A THT pad is 2–3 mm. The
>   reading averages pad, laminate, iron and background — it cannot resolve the
>   thing being measured, at any distance.
> - **Emissivity.** Consumer guns assume a matte surface (~0.95). Shiny solder and
>   ENIG gold sit nearer 0.05–0.2, so the gun largely sees *reflected ambient* and
>   reads far low — it will happily report ~150 °C on a pad genuinely at 250 °C.
>
> The gun stays useful for **bulk board temperature** (FR4 is matte, close to the
> assumed emissivity) — that is how you confirm a preheat plate is working. It is
> not a pad thermometer.

**Use the solder itself as the thermometer.** A phase change at a known temperature
beats any instrument here: if eutectic leaded solder flows, that joint is above
183 °C by definition. No calibration, no emissivity, no spot size.

**And for these THT pads the acceptance is barrel fill, not surface melt.** Solder
has to wick *up through the plated hole* and form a fillet on the **opposite** side
(IPC-A-610 class 2 wants ~75 % vertical fill). That is the unambiguous "the whole
joint reached temperature" signal, and it is exactly what a plane-starved pad fails:
you get a shiny blob on the iron side and nothing on the far side. Surface-melt alone
will lie to you here.

Three outcomes, not two:

| result | what it means | action |
|---|---|---|
| Wets **and fills through** in **≤3–4 s** | the plane is not winning | **No preheat.** Skip the 853A. |
| Only wets after **~8–15 s** | marginal | **Treat as a fail.** It passes on one joint, but there are ~16 XT30/XT60 plus Q1, SW1 and four buck stations to go — cumulative dwell is precisely how pads lift and laminate cooks. |
| Never wets; solder balls and sits | conduction into the plane exceeds what the iron delivers at liquidus | **Preheat mandatory.** |

Two things worth trying before spending anything:

- **Flux is a heat-transfer aid**, not just a cleaner — a fluxed joint conducts into
  the pad noticeably better than a dry one. Be generous on these six pads.
- **The Bambu P1S bed is an owned 100 °C contact plate.** Per §2 a contact plate only
  serves a face that is still bare — **stages 1–4**, which is exactly where **L1**
  lives, the hardest SMD joint on either board. Lay the board top-face-down on the
  bed with **kapton or foil between it and the PEI** so flux and solder never touch
  the sheet. 100 °C is the low end of the 100–130 °C target, but it removes ~80 °C
  of gradient for free. It does **nothing** for stages 7–8 (both faces populated by
  then), which is where the three 14 A pads are — so it does not replace the IR
  decision, it may just make stage 4 a non-event.

---

## 3. Population order

Ordering rules, in priority: **low profile before tall** (the board must sit
flat on the bench for every later joint), **small thermal mass before large**
(a preheated board makes small parts harder, not easier), **heat-sensitive and
plug-in modules last**, and **nothing that blocks access to a pad you still
have to reach**.

**Every stage ends with clean → inspect → rework, before the next one starts** (§2a).
Not a tidiness step: the flux is no-clean and its residue is glossy, so shiny — the
whole correctness criterion — cannot be read until the board is cleaned. Deferring it
to the end also defeats the ordering rules above, because by then the pad you need to
redo is behind a tall part on a board that no longer sits flat.

Side column is which face the **body** sits on. Grouped to keep flips to a
minimum: bottom SMD, then top SMD, then THT.

> **BENCH STATE — stages 0–9 COMPLETE on the power board (2026-08-15).
> Next is the §6 HARD GATE, then stage 10.** Every SMD part on both boards placed and
> measured (0–6, 08-09); switches (7), all 16 XT30s + `J1` + `Q1` (8), and all 8
> electrolytics (9) done 08-14/15.
>
> ⚠️ **A real short was found and cleared at stage 8/9** — `M1`'s wiring tied
> `VBAT_PROTECTED` to GND. See `../wiring/README.md` for the signature. It was caught by
> the pre-stage-9 check *one stage before* ~5470 µF would have hidden it.
>
> ⚠️ **This file is the PLAN. The bench RECORD lives in Notion** — *🔧 Soldering /
> Assembly Steps*, child of the *Power Board v6 Build Log*. Where the two disagree,
> **Notion wins**: it is written at the bench as work happens, this is written from
> the board files. The ticks below are a convenience and they have gone stale before —
> on 2026-08-13 this table and `STATUS.md` both still read "stage 1 was the last thing
> done", four stages behind, and `STATUS.md` was steering the next bench action off an
> expectation Notion had already struck out (see §6). Check Notion before believing a
> tick here.

| stage | side | what | why here |
|---|---|---|---|
| **0** | — | ✅ **DONE 2026-08-01** — bare-board: continuity `VBAT`↔`VBAT_PROTECTED` open (SW1 not fitted), no `VBAT`–`GND` short | Cheapest possible fault-find. A plane short after 33 THT parts is a nightmare. ⚠️ Applies to **the board it was run on** — five of each were ordered, so if the meter went on a spare rather than the build board, this is not carried over. Re-run on the actual build board before stage 1 if in doubt; it costs one minute. |
| **1** ✅ **DONE 2026-08-02** (15 power 0603 + 3 logic 1k) | **B** | Bottom 0603: R2–R9, R11–R16, C7 (+ logic R3–R5) | Smallest, flattest, most numerous, and all on one face — do them in one sitting with the top still bare. |
| **2** ✅ | **B** | Q2–Q4 (SOT-23) | Same face, still small, still cold. |
| **3** ✅ | **B** | U8 (SOIC-8) — and U7 (SOIC-14) on the logic board | Fine-pitch, wants flux + drag or wick. Before anything tall spoils the iron angle. **The stage most likely to want hot air for a bridge.** **Includes the `U8` 8↔4 bypass tack — see below.** |
| **4** ✅ | **B** | **L1** (12×12 SMD inductor) | Last of the bottom SMD. Plane-tied both sides → fat tip. Last stage where the top face is bare, so the last one a *contact* plate could serve (§2). |
| **5** ✅ | **F** | Top SMD: D1 (SOD-123F), R17, R\_gs1, C\_gs1 (+ logic C1, FB1) | Flip once. Only 4 top-side SMD parts — mind D1 polarity. |
| **6** ✅ | **F** | Low THT: J2, M1, J8, J20 (+ logic JP1, J9, J10, J21, J11, J20) | Headers and JSTs seat flush; do them before the board stops sitting flat. |
| **7** ✅ | **F** | SW1, SW2 terminal blocks | SW1.2 is a 14 A plane pad. Still low profile, so do it before the tall connectors crowd the iron. |
| **8** ✅ | **F** | XT30 ×8 + XT60 J1, buck stations U1–U4, **and Q1 (TO-220)** | The bulk of the high-current THT, plus Q1 — pad 3 is a 14 A GND inject. **Last preheat stage; see the note below.** Soldered from the bottom face, which already carries 20 SMD parts — hence C1–C6 must still be off. |
| **9** ✅ | B + F | Electrolytics: C1–C6 (bottom), C8–C9 (top) | Tall, polarised, **~105 °C-rated — below the 100–130 °C board preheat.** After every preheat joint, and after stage 8 because the bottom cans would block access to stage 8's solder side. |
| **10** ⏭ **NEXT — after the §6 gate** | **F** | Modules: **U9–U12** (INA226 ×4 — see §4, U12 is the L2 monitor), U6 (Teensy 4.1), U12-logic (Nano) | Heat-sensitive, tallest, and the parts you most want to be able to remove. Socket where possible. Note `U12` names *different* parts on the two boards: INA226 on power, Arduino Nano on logic. **Includes the `OE_TX`/`OE_RX` pull-up bodge on the logic board, before the Teensy goes in — see below (#434).** Gates 9a and 9b (§6) come first. |

### 🔴 Stage 3 also carries a bodge: `U8` has NO supply decoupling on the board

Verified from `nova_pcb_v6_power_v2.kicad_pcb` 2026-08-06 by full capacitor census, with
a negative control: **C1–C5** sit on `V7V5_LEG`/`V12_HIP`, **C6** on `V12_L2`, **C8/C9**
on `VBAT_PROTECTED`, and **C7 100nF is `VSENSE`↔GND — the sense filter, not a bypass.**
Scanning every footprint for one touching both `V5_AUX` and GND returns only `J2`, `J20`
and `U8` itself. **No two-pad part decouples `V5_AUX` anywhere on the board.** `U8`'s
supply pin is fed from `J2`'s UBEC down a wire with nothing local to it.

So a **100nF hand-tack across `U8` pins 8 (`V5_AUX`) and 4 (GND)** is a required build
step, not a nicety — without it the comparator trips are liable to chatter.

**It cannot be a plain 0603 bridge.** Pins 8 and 4 are **6.25 mm apart** (pin 8 at
x 91.905/y 130.525, pin 4 at 88.095/135.475) and an 0603 spans 1.6 mm. There is no GND
via nearby — the board has only **four** GND vias and none are close — and the nearest
GND pad is `Q2`.2 at 4.8 mm, still too far. So it needs a link: tack the 0603 to pin 8
and run a fine wire to pin 4. **Pull two or three strands out of the solder wick** for
that link — pre-tinned, ~0.1 mm, and far less likely to lever the 0603 off its joint
than the 22 AWG solid. Keep the loop short and flat, then confirm **4→8 ≈ 9.83 k**
(§6) — ~0 Ω means the tack shorted the rail.

⚠️ **Do not carry this bodge to `U7`.** The logic board's `C1` 100nF is a real routed
part on `GND`↔`+3V3` (stage 5). U7 is decoupled by design; U8 is not.

### 🔴 Stage 10 carries a bodge on the LOGIC board: pull-ups on `OE_TX` / `OE_RX` (#434)

Added 2026-09-25. Read from `nova_pcb_v6_logic.kicad_pcb`: `OE_TX` touches only `U6`.5 and
`U7`.1, and `OE_RX` only `U6`.6 and `U7`.4. **Nothing holds either high** while the Teensy is
booting, being flashed, or has not yet configured the pins. They are the active-low output
enables of both '125 gates, so both gates can drive the servo bus at once in that window. This
is a different bodge from the `U8` one above. `U7`'s decoupling is fine.

**Fit two 10k resistors, `U7`.1 → `+3V3` and `U7`.4 → `+3V3`**, at stage 10 before the Teensy
goes in. Nearest `+3V3` points, from the board file (logic board, F.Cu):

| from | nearest `+3V3` | span |
|---|---|---|
| `U7`.1 `OE_TX` (159.53, 66.19) | `U7`.14 (164.47, 66.19), straight across the package | 4.94 mm |
| `U7`.4 `OE_RX` (159.53, 70.00) | `U7`.10 (164.47, 71.27), diagonal | ~5.1 mm |

⚠️ **Straight across from `U7`.4 is `U7`.11, which is unconnected**, not `+3V3`. Do not land
the second resistor there. Other `+3V3` pads if the leads get crowded: `U7`.13 (164.47, 67.46),
`C1`.2 (165.47, 62.77), `R7`.1 (167.18, 72.00). Neither span fits an 0603 (1.6 mm). Use the
`U8` method: tack the resistor at the `+3V3` end and run a wick-strand link to the signal lead.
An axial resistor laid across the package would also span it; whether one is on hand is
unverified. Flux, and watch for bridges to `U7`.2/.3/.5, the neighbours at 1.27 mm.

**Check, with the Teensy OUT of its socket:**

1. Unpowered: `U7`.1 ↔ `J20`.5 = **10k**, `U7`.4 ↔ `J20`.5 = **10k**. With the Teensy out, the
   bodge resistor is the only path to `+3V3` on either net. ~0 Ω = bridged to a `+3V3` pin.
2. Powered: **J20 ribbon unplugged**, bench supply **3.3 V, 20 mA limit** into `J20`.5 (+) /
   `J20`.3 (−). With the Teensy out, nothing else supplies `+3V3` (its only source is
   `U6`.T3V3O). **`U7`.1 and `U7`.4 both read ~3.3 V (high).** A pin reading 0 V has no pull-up.

**Result:** _owed — not yet fitted._

### Per-stage parts, with VALUES

Read out of the board files 2026-07-30. **The side column in the table above is
power_v2**; the logic board is 19 top / 3 bottom (R3, R4, R5), so its parts are
listed per stage below rather than by that column.

Values matter more than references here: R2..R17 are eight different values in
one 0603 reel family, and a swapped divider resistor moves a trip point rather
than failing loudly.

| stage | power_v2 | logic |
|---|---|---|
| **1** B 0603 | R2 100k · R3 22k · R4 11.3k · R5 10k · R6 12.1k · R7 10k · R8 10k · R9 10k · R11 4.7k · R12 4.7k · R13 10k · R14 470k · R15 1M · R16 100k · C7 100nF | R3 1k · R4 1k · R5 1k |
| **2** B SOT-23 | Q2 · Q3 · Q4 — all BSS138 (`_cutoff` / `_estop` / `_jetcut`) | — |
| **3** SOIC | U8 LM393 (**B**) | U7 74LVC125 (**F** — top side, not bottom) |
| **4** B | L1 22 µH (SRR1260-220M) | — |
| **5** F SMD | D1 BZT52C18 18 V zener · R17 10k · R_gs1 100k · C_gs1 0.47 µF | C1 100nF · FB1 600R ferrite · R1 22R · R2 1k · R6 1k · R7 10k |
| **6** F low THT | J2 (UBEC 5V aux) · M1 (voltmeter tap) · J8 (servo-bus JST) · J20 (interboard) | J9 · J10 · J11 · J20 · J21 · JP1 |
| **7** F | SW1 rocker · SW2 e-stop (screw terminals) | — |
| **8** F high-current | J1 XT60 · J3–J7, J12, J13, J14 XT30 · U1–U4 buck stations · Q1 IRLB3034PBF | — |
| **9** electrolytics | C1–C5 1000 µF 25 V (**B**) · C6 470 µF (**B**) · C8, C9 470 µF (**F**) | — |
| **10** modules | U9 INA226 leg 0x40 · U10 hip 0x41 · U11 Jetson 0x44 · **U12 L2 0x45** | U6 Teensy 4.1 · U12 Arduino Nano |

`C_gs1` 0.47 µF and `D1` are the Q1 gate-harden network (`order-list.md` §97-102,
ordered 2026-06-22). Note that list still says "board edit still pending" — the
edit is done; the parts are on the board.

⚠️ **Fit the values in the table, not the ones in the older notes.** Several
places (the Notion build log's "Pending board edit", early review text) still say
*R17 = 100 Ω, D1 = BZT52C15 (15 V)*. **As built and as ordered: `R17` = 10k,
`D1` = BZT52C18 (18 V).** The 2026-06-18 analysis rejected 100 Ω outright — clamp
= Vz + Iz·Zz, so a 33 V spike gives 100 Ω → ~21 V, **over the IRLB3034's 20 V
Vgs limit**; 10 k → 18.04 V. Also note `C_gs1` is marked **"474" = 470 nF**;
a part marked "470" is 47 pF and gives you no soft-start at all.

### Polarity and orientation — getting these wrong is destructive

| part | the trap |
|---|---|
| **J1 XT60, J3–J7 / J12–J14 XT30** | **pad 1 = NEGATIVE, pad 2 = POSITIVE**, uniformly across all 9 AMASS parts — re-read from the board file 2026-08-13, 0 exceptions. `J1.1 = BATT_NEG`, `J1.2 = VBAT`. Do **not** assume pad 1 is +. On the board, **pad 1 is the roundrect pad, pad 2 is the round one**. ⚠️ **`J1` is the ONLY XT with no `+`/`−` silk** — see the row below. This exact reversal has been caught before on this board. |
| **`J1` specifically — meter it, do not eyeball it** | All eight XT30s carry `−`/`+` silk text (checked: every mark lands on the correct pad). **`J1` carries none** — its silk is body outline only. The outline *is* asymmetric (two chamfered corners at the pad-1/negative end, square at pad-2/positive, matching the XT60 housing's own chamfer and the "flat = +" rule), but that cue is hidden the moment the connector sits on it, and the part drops in 180° out perfectly happily on symmetric 4.5 mm drills. **This is worse than a reversed pack: `BATT_NEG` is not GND — it runs to `Q1`'s drain — so fitting `J1` rotated swaps the nets UPSTREAM of the reverse-polarity protection and defeats it.** Identify by continuity against parts already fitted: **`J1`.2 `VBAT` → rings to `SW1`.1** (stage 7); **`J1`.1 `BATT_NEG` → rings to `D1`.2 / `R_gs1`.2 / `C_gs1`.2** (stage 5) **→ until the §6 gate 9a rework (#429, 2026-09-25) moves those three ends to GND. After it, use `J1`.1 → `Q1`.2.** ⚠️ And the discriminator that catches the intuitive error: **`J1`.1 will NOT ring to GND.** Probing for ground on the negative pad finds nothing and invites you onto the wrong pad. |
| **C1–C9 electrolytics** | Polarised, and split across both faces (C1–C6 bottom, C8/C9 top), so "the stripe faces the same way" is not a single rule — check each against its own silk. |
| **D1 BZT52C18** | Zener, SOD-123F. Cathode band. Backwards it clamps nothing and conducts the wrong way. |
| **Q1 IRLB3034PBF** | TO-220-3. Its pad 3 is the 14 A GND inject; pad 1 is `Net-(D1-K)`, pad 2 is `BATT_NEG`. **⚠️ The TO-220 TAB is bonded to the drain = `BATT_NEG`, not GND** — and `SW1` switches only the positive rail, so the tab is live whenever the pack is plugged in, switch off included. Bolting it to a grounded chassis or a shared heatsink shorts drain→source and **silently, permanently bypasses reverse-polarity protection**. Mount isolated or free-standing; if it is ever heatsinked, mica/silpad + shoulder bush and ~~meter tab-to-GND for an open~~ **meter tab-to-CHASSIS for an open** first. ⛔ **The struck-out wording is wrong and would fail a good board:** tab-to-*board*-GND is asymmetric by design — Q1's body diode runs source→drain, so red on `Q1`.3 conducts (~0.5 V in diode mode) and red on the tab reads OL. **The asymmetry is the pass; ~0 Ω both polarities is the failure** (drain-source shorted, protection already gone). ✅ Confirmed asymmetric on the build board 2026-08-16 (§6). Also note the tab is internally the same metal as pin 2, so tab↔pin 2 is 0 Ω by construction and tests no solder joint. |
| **U8 LM393 / U7 74LVC125** | SOIC pin-1 dot. **U7 is on the logic board TOP face**, U8 on the power board bottom — do not carry one assumption to the other. |
| **U9–U12 INA226** | Off-board modules on a 4-pin header: `+3V3 / GND / SCL / SDA` at −5.08 / −2.54 / 0 / +2.54 mm. Rail current does NOT pass through the board. |
| **U6 Teensy / U12 Nano** | Orientation set by the USB end. Socket if undecided — see §7. |

### All preheat work finishes at stage 8 — this constrains the order

If preheat turns out to be needed (§2), it applies to **L1, SW1.2, Q1.3, U1.4,
the XT30/XT60s and the buck stations** — stages 4, 7 and 8. Every one of those
is done before an electrolytic goes on, because a ~105 °C-rated cap sitting on a
board held at 100–130 °C is being stressed by the very step that is meant to
protect the joint. Same logic for the plug-in modules in stage 10.

So the rule is not "tall parts last" for its own sake: **the board must be free
of anything temperature-limited for as long as it might still need to be hot.**
If a preheat-requiring joint has to be redone later, take the electrolytics off
first rather than preheating around them.

**Do not populate: U5 (power board).** See §4 — the reason changed.
**U12 DOES get populated** as the L2 rail monitor at 0x45 — also §4.

---

## 4. The arm rail (U5 / U12) — status corrected 2026-07-29

`pre-power-on-validation.md` §9 (written 2026-06-14) lists two blockers against
populating U5. **Both are closed on the ordered v2 board.** Verified by reading
pad nets straight out of `nova_pcb_v6_power_v2.kicad_pcb`:

| gap as written | actual on v2 |
|---|---|
| "arm rail has no exit — `V7V5_ARM` = `U5.4` only, single-pad net" | **`J14.2 = V7V5_ARM`.** The rail has an off-board XT30. |
| "🔴 arm buck is UNGATED — `U5.EN` tied to `VBAT_PROTECTED` = always-on" | **`U5.3 = EN_BUCKS`**, byte-for-byte the same net as `U1.3`. Gated by e-stop Q3 **and** hardcut Q2. |

So U5 is **DNP for scope, not for safety** — there is no arm yet. That is
a materially different instruction from "populating this is a crush hazard",
and §9 should be re-labelled rather than left to frighten the next reader.

### ⚠️ But U12 is a different case — POPULATE IT (corrected 2026-07-31)

**U12 is not an arm part any more.** Grouping it with U5 above is stale, and
following it would leave a rail unmonitored:

- All four INA226 slots are **electrically identical** — pads 4/5/6/7 =
  `I2C_SDA` / `I2C_SCL` / `+3V3` / `GND`. Nothing about the U12 footprint is
  arm-specific; current sense is off-board through the module's own terminals
  either way.
- The 4th INA was **reassigned to the L2 LiDAR rail on 2026-06-30** (commit
  `5fc5eba`) — L2 is live, nav-critical and brownout-sensitive, whereas an INA on
  the DNP arm rail would read nothing.
- **The firmware already expects it.** `platformio.ini:41` has
  `-D NOVA_INA226_L2` **enabled**, `ina226_telemetry.h:26` declares
  `INA226_ADDR_L2 = 0x45`, and `/power_rails` was widened 9 → 12 floats with
  L2 v/a/w at `[9..11]`. Leave U12 empty and those three publish nothing.
- You own **4 modules and no spares** — the 4th is not a shelf spare, it is this.

**Action:** fit U12 at stage 10, bead it to **0x45 (A0 + A1 → VS)**, and wire its
`IN+`/`IN−` inline in the **L2 12 V** harness. The arm, when it exists, gets a
**5th** module at 0x46 on the same bus — no board change.

---
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

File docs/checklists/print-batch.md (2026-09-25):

# Print Batch Checklist (v6 full set)

From the 2026-07-06 batch-questions review. The caliper prereqs are now
CLEARED (Jetson heatsink 34.9, D456 rear pattern confirmed, pack 510 g, 5191
= external mount) — so floor_plate / battery_pocket no longer risk a re-print.

**Every print gets a record in `docs/print-records/`** (`slice_plate.py` writes
it going forward; commit it when the plate is actually printed — the 19
`backfill-<part>.json` records there are hand-authored exceptions for prints
that predate this, see that directory's README) — that is the only way "which
revision is this bench part?" stays a diff instead of an archaeology exercise
(see `~/claude-memory/patterns/physical-parts-drift-from-the-repo.md`).

## ✅ RESOLVED 2026-07-13 — servo disc-interface dims verified (issue #85)

First-article caught one wrong ASSUMED servo dim: idler wheel center hub **Ø8.8**
(not Ø6) bottomed the Ø7 `WHEEL_CTR_D` relief → **fixed → Ø9.5 (#84)**. The rest
now CALIPERED off the real STS3215 and confirmed matching:
- `HORN_OD` 20.0 ✓ · `WHEEL_OD` 20.0 ✓ (both discs measured 20mm)
- `HORN_CTR_D` 6.5 relief ✓ — real retention-screw head **Ø5.1** (0.7mm/side clear)

**ALL leg parts now clear to print** — reprint `coax`/`coax_hfe_plate`/`femur`/
`knee_arm`/`shoulder`/`shoulder_plate` (+L) from the **#84 branch** (has the
wheel-hub fix). `tibia`/`strap`/`knee_bumper`/TPU/chassis were never affected.
(Density calibration + a full first-article grip check still owed per BOM/#5.)

## Δ since 2026-07-06 (head re-arch + fit/structure session, 2026-07-07)

**RETIRED — do NOT print:** `l2_mast`, `d456_head` (→ folded into `head`),
`hood` (→ official Jetson case), `tibia_pad` (misplaced → `knee_bumper`),
`spacer` (board in the case), `jetson_cowl` (→ right-angle plug adapters, #41
2026-07-10).

**NEW parts:** `head.scad` (fwd integrated head, PA6-CF), `neck_bracket.scad`
(front-shoulder-deck adapter, PA6-CF), `knee_bumper.scad` (TPU collapse guard),
`l2_adapter.scad` (L2 accessible-mount plate — the L2 bolts to it on the bench,
2 of the 4 L2 bolts are unreachable on the assembled head; access audit
2026-07-08), `head_ear.scad` ×2 (fennec ears / WiFi-antenna masts, bolt-on),
`control_pod.scad` (rear-top E-stop + OLED pod — re-homes them after the hood
was retired; bolts to the riser rear wall; 2026-07-08).

**CHANGED → re-print (old copies are stale):** all 6 legs (coax/femur/tibia
+ mirrors — new anti-rotation ribs in the servo pocket), `riser_bay` (head
interface removed 2026-07-07 + control-pod mount pad / grommet / guard exception
added 2026-07-08).

**⚠ NOT print-final:** `head` — functional + gate-clean, but the FENNEC styling
(STYLE=true ears) is a FIRST PASS (L2 skull shroud / eye accent / snout still
TODO) and its L2 (Ø51) + D456 mounts are gate-clean but BENCH-UNVERIFIED vs the
real parts. Print it in Wave 1 as a fit-check article, not the final head.

## Δ 2026-07-10 (AUD-12 / AUD-12b — head-boss void + battery-lead notch)

**⚠ RE-PRINT if you already have an article:** `head.scad` — the USB-C column
channel used to run straight through the rear boss, voiding the +y pair of
the 4 breakaway heat-set inserts (0.0mm floor/wall, measured) — an ALREADY
PRINTED head from before this fix has 2 of 4 head→neck_bracket bolts with no
real insert backing. Channel rerouted (shares the L2 cable bore below the
boss top instead); mouth of the L2/D456 cable bore also gained a 0.75mm
chamfer at the x121 breakaway plane. `leg_v6/shoulder.scad` — the
battery-lead notch (flange bottom, x±10) is now chamfered on all 4 nominal
edges at both mouths (was a raw 90° PA6-CF corner); an already-printed
shoulder has the sharp version. Both re-render clean via `build_all.sh`.

**NEW part:** `chassis/lead_notch_grommet.scad` (TPU 95A) — edge liner for
the (now-chamfered) battery-lead notch, same family as `case_slot_grommet`.
~0.2 g (small — check the slicer doesn't drop stray islands at that size).

## 0. Open before starting (user)

- [ ] PETG-CF spool on hand? (buy if not — or all-PA6 and accept warp
      risk on the 127 mm riser lid)
- [x] **TPU 95A on hand — SETTLED 2026-07-31 by having printed with it.** (~100 g
      budgeted, external spool — AMS won't feed.) This had been contradicted across
      three docs: `work-schedule.md` said ✅ on hand, this line said unknown, and
      `master-bom.md` listed only PA6-CF. Resolved in favour of ✅ — see §1b.
- [ ] ~1.5 kg PA6-CF + ~0.6 kg PETG-CF total — enough stock?
- [ ] Shoulder lightening windows (backlog #27): rec DEFER one rev —
      shoulder just took feet + bosses + gussets, prove it first
- [ ] Servo SKU audit (#23) done? (independent of printing but same bench
      session — label hip vs leg units)
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

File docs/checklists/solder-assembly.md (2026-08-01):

# Solder / assembly — see `hardware/pcb-mods/BUILD_PLAN.md`

**This file is a pointer. The canonical build sequence is
[`../../hardware/pcb-mods/BUILD_PLAN.md`](../../hardware/pcb-mods/BUILD_PLAN.md).**

## Why this is a stub

An earlier pass in this session wrote a full parallel populate checklist here
before noticing `BUILD_PLAN.md` (2026-07-29/30) already existed and was better:
11 stages instead of 8, an off-board component map with wire gauges, per-stage
gates, and the tip-per-stage table.

Worse, the two used **the same word "stage" for different steps** — this file's
"Stage 4" was low-profile top-side THT, `BUILD_PLAN`'s stage 4 is L1. Two bench
documents disagreeing on step numbers is the kind of seam that costs a board, so
this one was retired rather than reconciled.

It also had a real sequencing error: it listed **L1 with the ordinary 0603s**.
L1 is a 12×12 mm plane-tied inductor and is the **hardest joint on either
board** — `BUILD_PLAN` correctly gives it its own stage, last of the bottom SMD,
because it is the final point at which a contact preheat plate could still reach
a bare top face.
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

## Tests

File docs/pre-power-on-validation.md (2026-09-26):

# Pre-Power-On Validation Checklist

The gap between "passes DRC" and "verified won't brown out / burn out under gait."
These are DESIGN-validation steps (not part-quality tests — those are in
ROUTING_HANDOFF.md Step 10). Compiled from the 2026-06-13 ultrathink electrical review.

Order: clear 🔴 before any board work, 🟡 during bench bring-up, ⚪ at checkout/assembly.

## 🔴 1. Logic board: schematic fixes + route (BEFORE fab)
Found in 2026-06-13 review. Schematic fixes first (GUI), then re-export netlist → route.
- [x] **R1/FB1 un-DNP** — were DNP in series in the only bus path = open bus. Now R1=22R,
      FB1=ferrite (done 2026-06-13). Need 22Ω 0603 + 0603 ferrite added to DigiKey order.
- [x] **+3V3 source FIXED** (2026-06-13) — Teensy 3.3V pad `T3V3O` added to U6 symbol (Power
      output) + wired to +3V3. Netlist verified: +3V3 = [U6.T3V3O, U7.10/13/14, J20.5].
      SN74LVC125A + 3× INA226 now powered.
- [x] **100nF decoupling at U7 DONE** (2026-06-14) — C1 (CC0603 100nF) across +3V3/GND
      placed next to U7 pin14, routed.
- [x] **Routed** (2026-06-14) via Freerouting headless (openjdk + freerouting-2.2.4.jar;
      pcbnew ExportSpecctraDSN → java route → ImportSpecctraSES). 24 nets, 154 tracks, 3 vias.
      Min thermal spokes 2→1 to clear GND starved-thermal. **DRC: 0 errors, 0 unconnected.**
- [x] **J20↔J20 net mapping VERIFIED matched** — both boards' J20 pin→net identical (straight
      ribbon = correct, no bus mirror). Remaining: visual key-orientation at assembly (shrouds enforce).
- [x] **E-stop sense to Teensy ADDED** (2026-06-14) — was: hardware e-stop (Q3) killed
      bucks but Teensy was blind (no ESTOP on J20, 12 pins full). Added J21 (Conn_01x02)
      → e-stop button's 2nd NC dry contact → Teensy pin 5 (`INPUT_PULLUP`) + GND. Dry
      contact = no level-shift; NC-to-GND = LOW idle, pressed/break/unplug = HIGH = e-stop
      (FAIL-SAFE). Routed F.Cu J21.1→U6.T5 (existing 154 tracks untouched). DRC 0/0,
      gerbers re-cut. Net auto-named `Net-(J21-Pin_1)` (label didn't stick; electrically
      correct). No power-board / J20 change.
- [x] **Firmware pins reconciled to board** (2026-06-14, teensy41_ci green) — board routes
      bus to Serial1 (pins 0/1), OE to 2/3, BATT_LOW to 4, e-stop to 5; firmware was on
      Serial2 7/8 / OE 5,6 / BATT_LOW 3 / ESTOP 2. Updated `main.cpp` defines +
      `feetech_bus.h` (Serial2→Serial1). I2C 18/19 already matched. **E-stop polarity
      flipped LOW→HIGH** (NC fail-safe; SafetyFSM already latches until /safety_clear →
      snap-back on release handled). Reconciliation was mandatory — old defines = dead bus.
- [x] **OLED (J10) integration fixed** (2026-06-14) — owned HiLetgo SSD1331 (7-pin, VCC
      2.8-5.5V = has onboard reg). Found 3 issues vs the board: (1) J10 pin order had CS/RST
      crossed vs the module → swapped on board (J10.5=OLED_RST, J10.7=OLED_CS); (2) Vcc was
      on NANO_3V3 (Nano's ≤50mA reg, often absent off-USB) → moved to **V5_AUX (5V)**;
      (3) Nano is 5V → its SPI logic over-drives the 3.3V-reg'd SSD1331 → added **5× 1k
      series R (R2-R6)** on SCK/MOSI/RST/DC/CS. Schematic + full re-route, DRC 0/0, gerbers
      re-cut. BENCH-VERIFY: if display still glitches, swap to Adafruit 684 (74LVC245+boost,
      5V VIN, DK 684-ND) — wire 7 pins to J10.
- [x] **U7 → SN74LVC125A (5V-tolerant)** (2026-06-14) — servo bus is 5V-TTL; the 74HC125 at
      +3V3 is NOT 5V-tolerant (input abs-max VCC+0.5=3.8V) → servo's 5V response over-drives
      gate2 input, clamp current ~54mA through R1's 22Ω = stress/damage. SN74LVC125A: same
      SOIC-14 pinout (drop-in), VCC 3.3V (max 3.6V — keep on +3V3, never 5V), inputs 5V-tolerant,
      outputs swing 3.3V (Teensy-safe). Correct whether bus is 3.3V or 5V. (Sch value was stale
      "74LS125" = 5V TTL, also wrong for 3.3V.) Value-only change, no reroute.
- [x] **Bus idle pull-up R7 (10k BUS_SIGNAL→+3V3)** (2026-06-14) — half-duplex push-pull bus
      floats during TX↔RX turnaround → gate2 input indeterminate / false RX bytes. R7 holds idle
      HIGH at 3.3V; 10k = idle bias only (drivers do edges), no speed penalty.
- [ ] (tidy) Add `no_connect` flags to 16 unused Nano GPIO pins — clears ERC noise
- [ ] 2oz outer copper selected for BOTH boards at PCBWay

## 🔴 1b. USB back-feed isolation (Teensy + Nano externally powered)
V5_AUX (UBEC 5V) feeds Teensy VIN + Nano +5V. Plugging USB to flash/debug WHILE battery
live = USB 5V vs UBEC 5V fighting on V5_AUX. (This is the ERC "two power outputs" conflict.)
- [ ] **Teensy 4.1: cut the VUSB↔VIN pad** (bottom of board, PJRC-documented) so USB does
      data-only when powered from VIN. Do this before first battery+USB session.
- [ ] **Nano:** never plug USB while battery-powered, OR add a series Schottky on the +5V
      feed. Confirm whichever before bring-up.

## 🔴 1c. Connector mating audit (BEFORE assembly — HARD GATE)
The board files only define what net lands on each connector pin; they CANNOT verify the
**physical part's** pinout/polarity. Every off-board connector below is correct on the BOARD
side (verified from the .kicad_pcb) — the open item is confirming the MATING part agrees.
Only rigid direct-plug modules force a board re-route; the rest are hand-wired, so the board
pin is the reference and you wire the cable/leads to match it. (Compiled 2026-06-14 after the
OLED pinout miss — that was a rigid direct-plug module, now fixed; this is the rest of the set.)

**🔴 High — a mismatch damages a part or shorts power:**
- [ ] **J11 WS2812B** — board: `1=+5V, 2=GND, 3=DATA`. WS2812B strip wire order varies; reverse
      5V/GND = fried strip. Crimp the JST-XH pigtail to match J11, and connect to the strip's
      **DIN** end (not DOUT). Verify with a meter before plugging in.
- [ ] **J8 servo bus** — board: `1=GND, 2=V7V5_LEG, 3=BUS_SERVO`. ✅ Matches Feetech STS3215
      standard (GND/VCC/Signal). NOTE: servo uses a 5264 connector, board is JST-XH — crimp
      your own JST-XH pigtail in GND/V+/Signal order (don't assume a pre-made cable's housing mates).
      Under the harness plan below, **J8's VCC pin (2) feeds nothing** — chain entry uses only
      GND + Signal; every servo's VCC arrives from its XT30 rail spur instead.
- [ ] **⚠️ DUAL-VOLTAGE SERVO HARNESS — FRY-CRITICAL, #1 fry path.** J8's bus signal is shared by all
      12 servos, but power is TWO voltages: **each haa (hip) = 12 V (IDs 1,4,7,10 — per-leg-sequential
      map, `joint_id_map.yaml`); each hfe/kfe = 7.5 V**. The chain runs haa→hfe→kfe per leg, so
      12 V↔7.5 V transitions occur WITHIN each leg (haa→hfe ×4) AND between legs (kfe→next haa ×3) =
      **7 boundaries**. A stock 3-wire daisy cable bridges VCC across a boundary → 12 V into a 7.5 V
      servo = fried. Plan (removes all 7 boundaries): **NO cable carries VCC servo-to-servo.**
      **How each servo gets power despite that:** the STS3215's two 3-pin ports are internally
      paralleled, and the servo doesn't care where each wire came from — so each servo-side plug is
      built from three sources: **VCC = spur from its local XT30 injection** (7.5 V J3–J6 for hfe/kfe,
      12 V from J7 for haa), **GND = common** (star ground), **Data = daisy from the previous servo**.
      Build recipe per link: take a stock Feetech 3-wire cable, **pull the VCC pin from the upstream
      end**, crimp the XT30-fed VCC branch into the servo-side housing (5264, NOT JST-XH). **Keep GND
      continuous through every daisy link** — it is both power return and the data line's signal
      reference; a GND that follows the signal wire = less noise. **Meter every servo VCC = its
      correct rail BEFORE the chain sees power** (§1c hard gate). Full spec:
      `hardware/wiring/README.md` dual-voltage section.
- [ ] **J20 interboard ribbon** — both boards' pinouts identical (verified). A 2×6 IDC ribbon
      can be built/plugged mirrored → 5V meets GND. **Meter-check pin1↔pin1 continuity** on the
      assembled cable before first power; confirm shroud keys are consistent.
- [ ] **U1–U5 Pololu bucks** (off-board, XT30 + EN wire) — board: `VIN=VBAT_PROTECTED, GND,
      EN=EN_BUCKS/EN_JET, VOUT`. Reverse VIN into a Pololu = dead module. Match each buck's
      VIN/GND/VOUT/EN silk to the wiring. **⚠️ Fixed-output variant per slot is a FRY RISK the board
      can't enforce — confirm F7 vs F12 on each physical module (see §1e).** Terminal rect pad = + .
      ⚠️ **The silk does not tell you the variant** — the module prints `reg34c` (a board-design
      number), not `D42V110F7`. **Confirm by measurement: VIN ~15 V current-limited, no load, read
      VOUT — 7.5 V = F7 → `U1`, 12 V = F12.** Label each module as you read it.
      ⚠️ **The enable pad is `ENA` or `ENB` and we have never recorded which.** `EN_BUCKS` has **no
      pull-up on the board** and the safety chain pulls it DOWN (`Q2`/`Q3` gate→`EN_BUCKS`,
      source→GND), so the correct pad is the one that **disables the module when grounded**. Test:
      VOUT up with EN unattached, then ground each pad in turn. Wrong pad = the e-stop does not cut
      the bucks, silently. See `../hardware/pcb-mods/BUILD_PLAN.md` §5.
- [ ] **XT connector GENDER on every harness end — decide by CONTACTS, not by the part name.**
      Board side per the FOOTPRINTS is `XT60-M` at `J1` and `XT30U-M` at `J3`–`J7` / `J12`–`J14`
      (verified 2026-08-13). Every cable end must be the *physical complement*.
      🔴 **AS BUILT, `J1` DOES NOT MATCH ITS FOOTPRINT** (bench-confirmed 2026-08-14). The fitted
      part is the **receiving housing with PINS** (`XT60-F`) — the opposite of every XT30 on the
      board, which are plug-in housings with SOCKETS. Accepted, not a defect: the holes are
      symmetric so it seats either way, and it is arguably the safer arrangement (see below). It
      changes what to build: **`J1`'s harness end is the plug-in/SOCKET half**, while every XT30
      harness end is the receiving/PIN half. Do not build all 17 the same way.
      Why it is safe as built: `J1`'s pins are dead when unmated (nothing feeds them from the board
      side), while the pack harness — live via the MRBF block — carries the recessed sockets. The
      rail XT30s are the mirror: the BOARD side is the live one when unmated, and it has the
      recessed sockets. Both ends up with the energised half recessed. ⚠️ **The "-M"/"-F" names are
      inverted for XT60**: the "male" housing is the smaller one carrying female **sockets**, which
      is why LiPo packs ship as "male" and still have recessed contacts. Reasoning from the suffix
      will get this backwards — hold the two parts together and check pins-vs-sockets.
      **The pack does NOT plug into `J1`** — it routes via the MRBF-30 block on ring lugs
      (`../hardware/pcb-mods/BUILD_PLAN.md` §5), so the pack-end and board-end genders are
      *independent*. Whatever `J1` ended up as, the harness's board end just needs its complement,
      and the XT60H order was a 10-**pair**, so both are on hand. Polarity is separately enforced:
      **+ (red) → flat side** per §1e, and the keyed housing then makes reversal impossible.
- [ ] **🔴 Rail cross-plug — 8 identical XT30s, TWO voltages, ZERO keying between them.** Read out
      of the board file 2026-08-13:

      | connector | net | volts |
      |---|---|---|
      | `J3` `J4` `J5` `J6` | `V7V5_LEG` | **7.5 V** |
      | `J7` | `V12_HIP` | 12 V |
      | `J12` | `V12_JET` | 12 V |
      | `J13` | `V12_L2` | 12 V |
      | `J14` | `V7V5_ARM` | 7.5 V (rail DNP) |

      Same part, same gender, same keying on all eight — the housing key enforces **polarity**, not
      **rail**. Nothing physical stops a leg harness going into `J7`, which puts **12 V into 7.5 V
      servos**: the same fry this document already guards against on the servo daisy chain, arriving
      by a different route. The four buck stations (`U1`–`U4`, 2× XT30 each) add eight more
      identical connectors to the same pool.
      **Mitigation is labelling, because there is no mechanical one.** Label **both ends** of every
      rail harness with rail name *and* voltage before first power, and meter each connector's rail
      at the board before mating anything to it.

**🟡 Medium — silent failure / safety-logic inversion:**
- [ ] **U9–U12 INA226 modules** — board connects I2C+power only (`4=SDA, 5=SCL, 6=VCC, 7=GND`).
      Confirm (a) module header order matches your dupont wiring, (b) **a unique I2C address per module via the
      A0/A1 solder bead — see the §1e table** (4 modules on one bus = must differ, or collision).
      **⚠️ Current-sense path — PCB has NO shunt** (the shunt resistors that once sat at R13/R14 were
      deleted — ⚠️ **those designators have since been REUSED for live safety-chain parts: `R13` = 10k
      e-stop pull-up `EN_SW`↔`V5_AUX`, `R14` = 470k hardcut hysteresis. Both MUST be populated.**
      Do not read this line as "leave R13/R14 off"): rail current must pass through each
      module's IN+/IN− screw terminals (onboard 2 mΩ), wired **inline in the harness**: source → IN+ → IN− → load.
      **Hip (J7) / Jetson (J12) / L2 (J13) = single XT30 → clean full-current insertion. Leg (0x40) stars into
      4× XT30 (J3–J6) ON the PCB → NO single total-leg-current point** — insert at U1 buck VOUT (cut VOUT→plane)
      for total, or accept partial/no leg-current telemetry (affects the stall load-monitor). Decide before
      trusting `/power_rails` leg data.
- [ ] **U6 Teensy 4.1 socket — pad→GPIO unverified (custom footprint):** board nets are all correct
      (RX/TX/OE_TX/OE_RX/SDA/SCL/BATT_LOW/ESTOP present), but the socket footprint's pad *positions* vs the
      real Teensy 4.1 pinout were reconstructed (PJRC card), not bench-verified. Seat a real Teensy and confirm
      GPIO **0/1=RX/TX, 2/3=OE_TX/OE_RX, 4=BATT_LOW, 5=ESTOP, 18/19=SDA/SCL** land on the matching traces.
      Wrong mapping = firmware drives dead pins (no fry; silent non-function).
- [ ] **SW2 + J21 e-stop contacts** — board expects **NC** (`SW2: GND↔EN_SW`; `J21: sense↔GND`).
      Fail-safe depends on NC, not NO. Identify the NC pairs on the Mxuteuk button; confirm it has
      a *second* NC block for J21. NO wiring → reads always-pressed or never trips.
      **Firmware:** Teensy ESTOP = pin 5 → J21.1 (contact-to-GND, no board pull-up) → set
      `pinMode(5, INPUT_PULLUP)` or pin 5 floats → unreliable read. (Separate sense path from the
      *hardware* kill SW2→EN_SW→Q3→EN_BUCKS, which de-energizes the bucks ~~regardless of firmware~~
      **→ corrected 2026-09-25, #430: independent of firmware, but NOT of `V5_AUX`.** `R13` 10k
      `EN_SW`↔`V5_AUX` is the only pull-up on Q3's gate (board file), so with the UBEC dead or
      unplugged a pressed E-stop leaves Q3 off and the bucks running. Bench step in §3 step 5.)
- [ ] **E-stop continuity check (both contacts, same press):** button released → J21 shorted
      (NC, contact-to-GND) → Teensy pin 5 reads LOW; button pressed → J21 open → pin 5 reads
      HIGH. Meter-check this on J21 directly, then confirm SW2 (the hardware path) also opens
      on the SAME press — one NC block failing to change state while the other does is the
      HB2-ES544 either missing its 2nd contact block or one block miswired.
- [ ] **TVS present, band toward +** — SMBJ8.5A ×2 on the leg (V7V5_LEG) XT30 injection
      pigtails, SMBJ13A on the hip (V12_HIP) injection pigtail (optional on V12_L2). Confirm
      each is soldered across the pigtail on the servo side with the banded (cathode) end to
      + before first power — reversed polarity shorts the rail instead of clamping it. See
      `hardware/wiring/README.md` "Regen TVS clamps".
- [ ] **JP1 (JP_BUS_MASTER) reachable after stack-up** — single config jumper, logic board
      TOP face at (160, 86), **same face as the socketed Teensy U6 + USB** (verified from
      .kicad_pcb). That face must mount outward for USB access → JP1 should be reachable; just
      confirm final stack orientation puts the Teensy face out, not into the gap. Flip to **A**
      once for servo-ID assignment, then back to **B** (default).
- [ ] **In-gap component heights** — confirm tallest parts facing the ~20 mm mezzanine gap
      (bulk caps Ø10×17 mm, INA226 modules) clear the M3×20 standoff gap (≤~17 mm target).

**🟢 Low — protected or bench-only:**
- [ ] **J1 XT60** — post-polarity-fix: `pad1=BATT_NEG(−)/chamfer side, pad2=VBAT(+)/flat side` (see §1e — was reversed, fixed 2026-06-29). ~~Q1 reverse-prot covers a slip, but confirm flat=+.~~
      **→ corrected 2026-09-25, #429: Q1 does NOT cover a slip on the board as built.** `D1` anode,
      `R_gs1` and `C_gs1` land on `BATT_NEG` (`Q1`.2, the drain), not GND (`Q1`.3, the source) —
      read from `nova_pcb_v6_power_v2.kicad_pcb`. With `J1` reversed, `D1` conducts forward and
      pulls the gate above the source, so Q1 turns on and passes the reversed pack. Treat a
      reversed `J1` as destructive until the rework and the reversed-`J1` bench test in
      `../hardware/pcb-mods/BUILD_PLAN.md` §6 gate 9a have both passed. Confirm flat=+.
      **This moves `J1` out of 🟢 Low** until 9a passes. (FMEA row: `power-chain-fmea.md#pc-01`.)
- [ ] **SW1** — confirm the physical switch is rated for full pack current (~15–18 A).
- [ ] **J9 FE-URT-1** — Pattern-A bench adapter only; confirm its data pin = MASTER_A if used.
- [ ] **Q1 IRLB3034** — TO-220 G/D/S = pin 1/2/3 (matches footprint); confirm tab = Drain.

## 🟠 1d. Power-board fixes from adversarial review (2026-06-26)
- [ ] **U8 LM393 — NO Vcc bypass cap on the board.** Hand-tack **100nF V5_AUX↔GND across U8 pins 8↔4** (0603 or axial) at assembly. V5_AUX also sets the trip VREFs (R4/R6) → an unbypassed comparator supply risks noisy/chattering 13.0/12.4 V trips. Not on the PCB; add by hand.
- [ ] **Solid-plane soldering tradeoff:** VBAT_PROTECTED (PWR.Cu) + GND (GND.Cu) are now **SOLID** pad-connected, and power-zone spokes widened (2.0 mm leg / 1.5 mm VBAT+HIP) — needed because the high-current pads (**SW1.2 14 A inject, U1.4 10 A leg VOUT, Q1.3 14 A GND inject**) were **thermal-relief 0.5 mm ≈ 6 A throats** (plane-only, no trace) that would overheat. Cost: those THT power pads (SW1, Q1, buck VIN/VOUT, GND THT) now **wick heat into the planes** → use a **fat tip (TS-C4) at 24 V / ~88 W, tip 400 °C**. ✅ **The "a bare 60–88 W Pinecil will struggle" prediction was TESTED 2026-08-01 and is WRONG for the THT pads:** `U1.4` wet in ~2 s with fill through to the far face and `Q1.3` (the 14 A GND inject) was easy and shiny on both faces, **with no preheat at all**. Preheat is not needed and is not being bought — see `hardware/pcb-mods/BUILD_PLAN.md` §2a. The prediction is still *untested* for **`L1`**, which is SMD and plane-tied on both sides (no barrel to wick).
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

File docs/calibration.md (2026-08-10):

# Calibration Procedures

Sensor and joint calibration for the modified NovaSM3 platform.

## Servo zero-position calibration — REAL PROCEDURE

Everything below is read out of the code it describes, not written from memory;
each step names the file that implements it.

**Status of the config the old text warned about.** `servo_homing/config.py` no
longer needs filling from CAD for most joints: all **8 hfe/kfe** entries carry
real hard stops and `placeholder=False`. The **4 haa** ids (1, 4, 7, 10) are
still `placeholder=True`, each with a `PLACEHOLDER_REASON` — and that is not a
value anyone can look up. `HAA_INBOARD_SIGN` is the inboard direction *in the
servo command frame*, which is unknowable until a real servo is watched moving.
Step 3 is how it becomes known. **Writing it by hand does not count (#161):**
the recorded confirmation is what unlocks the window, not the number.

### 1. Bring up the bench profile

```
ros2 launch nova_ops bringup.launch.py profile:=bench
```

`bench` starts `firmware_tables` and requires a preflight PASS. That node is
what publishes `joint_limits` / `hfe_envelope` / `limp_pose` to the Teensy —
until it has, the firmware's per-joint clamp is wide open (0..4095) and the
#145 controlled limp falls back to instant torque release.

### 2. Home the 8 hfe/kfe joints

```
ros2 launch nova_calibration servo_homing.launch.py
```

Drives each joint to its self-collision hard stop under STS3215 load feedback
and records the offset. Joints still marked `placeholder=True` are **skipped**,
so the 4 haa are untouched here — if you see *"done — 0 joints homed
(all skipped/failed)"* (`servo_homing/node.py:167`), the config is not what this
document describes and you should stop.

Writes `~/.nova/calibration/servo_offsets_<stamp>.yaml` and refreshes the
`servo_offsets_latest.yaml` symlink (`servo_homing/storage.py`).

### 3. Confirm each haa sign — ON HARDWARE, ONE LEG AT A TIME

```
ros2 run nova_calibration confirm_haa_sign \
    --joint FL --observed inboard \
    --assembly 'leg_v6 rev2 / FL / servo 1'
```

- `--joint` — `FL/FR/RL/RR` or the haa bus id (1/4/7/10)
- `--observed` — **which way the FOOT actually swung, as you watched it**
- `--assembly` — which physical leg/servo this was seen on; it is recorded
- `--probe-deg` — defaults to `MAX_PROBE_DEG`, which is **half** the runtime
  ±15° clamp. The tool **refuses** a larger value rather than silently
  clamping it.
- `--reverse` — probe toward decreasing raw counts instead of increasing

Repeat for all four. Each run appends through the same write path as step 2.

**Why haa is the one that carries hardware risk:** inboard tucks a leg under the
belly where the LiPo sits. That is why the runtime clamp is a conservative
symmetric ±15° until confirmation, and why the probe is bounded to half of it.

### 4. What unlocks, and how to check

`confirmed_haa_sign()` (`nova_ops/safety_envelope/limits.py:173`) reads the
artifact; `load_default_limits()` builds the per-bus-ID table from it. Once all
four are recorded:

- the haa window widens from symmetric ±15° to the asymmetric
  15-inboard / 40-outboard envelope,
- `choreo.stand.pose_for('sit'|'down')` stops raising and returns the splay
  poses (they need ~40° outboard),
- `safety_envelope.limp_pose.build_limp_pose_data()` stops returning `None`, so
  the Teensy finally receives a real `limp_pose` table and the #145 controlled
  limp arms instead of falling back to instant release.

Quick check without moving anything:

```
python -c "from nova_ops.safety_envelope.calibration_io import read_calibration; \
           from nova_ops.safety_envelope.limp_pose import build_limp_pose_data; \
           print(build_limp_pose_data(read_calibration()))"
```

`read_calibration()` defaults to `DEFAULT_CALIBRATION_PATH`, the same artifact
`tables_node` reads (`calibration_io.py:36,124`).

`None` means at least one leg is still unconfirmed or uncalibrated — that is the
fail-safe, not a bug.

## Will cover
- Leg kinematic calibration (link lengths, joint offsets in URDF/xacro)
- IMU calibration: D456 IMU intrinsics + L2 IMU bias estimation (MPU-6050 cut per BOM v3.5)
- RealSense ↔ Unitree L2 extrinsic calibration (hand-eye or target-based)
- Arm tool-tip calibration (when arm is mounted)
- EKF tuning (`robot_localization` covariance matrices)
- Calipers — used for direct link-length measurement during leg redesign

> **Status:** placeholder — populate during Phase 2.

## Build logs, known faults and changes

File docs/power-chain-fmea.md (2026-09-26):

# Power-chain FMEA — v6 power board (4S LiPo → Q1 → SW1 → bucks, safety chain)

2026-09-25. Scope: pack → MRBF-30 → `J1` → `Q1` → `SW1` → `VBAT_PROTECTED` → bucks `U1`–`U4`, the
`V5_AUX` safety chain (`U8` LM393, `Q2`/`Q3`/`Q4`), telemetry. Board = `hardware/pcb-mods/nova_pcb_v6_power_v2/`,
copper frozen, so each row has a v6 bodge and a v7 fix. Nets come from a `kicad-cli sch export netlist`
of the current schematic, not from the docs. **Severity:** 5 = fire, pack short, or a safety function
lost silently · 4 = safety function degraded, or many parts or the pack damaged · 3 = one module or the
pack damaged, needs misuse or bad luck · 2 = wrong data, nuisance, bring-up confusion · 1 = cosmetic.
Nothing here is bench-measured yet. The **Measured** column is blank for that reason.

| ID | Element | Failure mode | Effect (local → system) | Detection today | Sev | Mitigation (v6 bodge / v7 fix) | Bench check (measure → pass) | Measured | Source |
|---|---|---|---|---|---|---|---|---|---|
| PC-01 | `Q1` IRLB3034 reverse-polarity FET | Gate network (`D1` anode, `R_gs1`, `C_gs1`) returns to `BATT_NEG`, which is Q1's **drain**, not its source. The `Q_NMOS_GSD` symbol calls pin 2 "S", but on a TO-220 IRLB3034 pin 2 is D. With the pack reversed, `D1` forward-biases, the gate sits at ≈V−0.7, and Q1 turns on as a source follower | ≈V−Vgs reaches `VBAT_PROTECTED`→`GND` reversed (≈13 V at a 16.8 V pack): `C8`/`C9` reverse-biased, UBEC, `M1`, every buck VIN → board + logic loss | **None.** Every continuity check passes and every doc calls Q1 "correct". The XT60 key is the only barrier. The MRBF ring lugs and bench clips have no key | 5 | v6: lift `D1`.A, `R_gs1`.2, `C_gs1`.2 off `BATT_NEG` and wire them to `Q1`.3 (GND). That is 3 SMD ends. v7: fix the symbol, and add a pin-map check (datasheet GDS vs symbol) to the fab gate | `J1` reversed from the PSU at 5 V / 20 mA, SW1 ON, UBEC + bucks + `M1` unplugged, ≤5 s. Measure V(`SW1`.2→`Q1`.3) and V(`J1`.1→`Q1`.3). **Pass:** \|SW1.2\| < 0.1 V and Vds ≈ 5 V. **Fail (predicted as-built):** SW1.2 ≈ −2…−3 V, Vds ≈ 2–3 V (≈Vth, not 0), PSU ~0.5 mA | | `01_battery.kicad_sch:1104-1111` (lib pin 2 = "S"), `:2162` (Q1); nets `BATT_NEG` = J1.1 Q1.2 D1.2 R_gs1.2 C_gs1.2; `Net-(D1-K)` = Q1.1 R17.2 |
| PC-02 | `U1` leg buck + leg harness | 12–16.8 V on the 7.4 V-class femur/tibia STS3215 (6–8.4 V). Causes: a D42V110**F12** fitted in the `U1` slot (the silk reads `reg34c` on every module), a buck high-side short, or a leg servo plugged into the `V12_HIP` harness | 8 servos (or 1) overvolted. The SMBJ8.5A harness TVS conducts and burns, so it does not protect | None on the board. Leg INA 0x40 reads voltage only, and only if IN− is tapped. The servos report their own supply V over the bus, but only after the damage | 5 | v6: read VOUT per module at 15 V in, no load, **before** any servo is attached. Label each module. Meter every servo plug. v7: OV comparator on `V7V5_LEG` driving `EN_BUCKS` | Each module at 15 V in, no load. **Pass:** U1 7.4–7.6 V; U2/U3/U4 11.8–12.2 V. Every femur/tibia plug 7.5 V, every hip plug 12 V | | `02_power_rails.kicad_sch:2939` (U1); `BOM.md:64-65`; `pre-power-on-validation.md:228-230`; `BUILD_PLAN.md:836-841` |
| PC-03 | `M1` / `J2` 2.54 mm headers (raw pack beside GND) | Bridge across M1.1↔M1.2 or J2.1↔J2.2 (pack short), or across J2.1↔J2.3 (16.8 V onto `V5_AUX`) | Pack short: hundreds of amps through 22 AWG and Q1 until the MRBF-30 clears. J2.1↔.3 kills the Teensy VIN (5.5 V abs max), the Nano, the OLED and the LEDs in one go | **It happened 2026-08-14 (M1).** It was found only by the 109.6 k it left at BATT_NEG↔GND | 5 | v6: Kapton at each pin base on both headers, plus strain relief. v7: series 10 k (or PTC) on the M1 sense tap; UBEC header at 5.08 mm pitch | SW1 OFF, UBEC + M1 off: M1.1↔M1.2 climbs to ≈121.5 k (R2+R3). **Pass:** >100 k in both polarities. **Fail:** <10 Ω | | `hardware/wiring/README.md:299-330`, `:411-451` |
| PC-04 | `V5_AUX` (UBEC), the only supply for the safety chain | UBEC dies or browns out, or `J2` comes unplugged | `Q3` gate bias (`R13`→V5_AUX), the `U8` supply and the `HARDCUT` pull-up (`R9`→V5_AUX) all go → `EN_BUCKS` released → **E-stop and hardcut both inert, bucks stay on.** The Teensy (VIN = V5_AUX) dies with them, so the servos hold their last goal with no controller | None. Nothing monitors V5_AUX, and the firmware dies with it | 4 | v6: no cheap bodge. Document it, and check V5_AUX before arming. v7: bias Q3/U8 from `VBAT_PROTECTED` through a local LDO, and make EN default-OFF (pull-down, actively enabled). #395's pull-up to V5_AUX has the same dependency | PSU 15 V, bucks on with no load, E-stop **pressed** (VOUT = 0). Unplug the UBEC at J2. **Pass (v7):** VOUT stays 0. **v6 expected fail:** VOUT returns to ≈7.5 V | | nets `EN_SW` = Q3.1 R13.1 SW2.2; `V5_AUX` = R13.2 R9.1 U8.8 J2.3; `HARDCUT` = R9.2 Q2.1 Q4.1; `06_safety_chain.kicad_sch:4125` (R13), `:3736` (R9) |
| PC-05 | E-stop → `EN_BUCKS` | E-stop pressed but the bucks stay on. Causes: EN wired to the wrong module pad (ENA vs ENB on `reg34c`); no board pull-up on `EN_BUCKS`; `EN_SW` harness shorted to GND; welded NC block | The robot keeps torque with the button latched: the primary safety function is lost silently | The J21 2nd contact tells the firmware the button moved, but **nothing reads `EN_BUCKS` back**, so a fault in the hardware path is invisible | 4 | v6: BUILD_PLAN's ENA/ENB ground test, then a functional E-stop test at every bring-up. v7: explicit EN pull-up (#395), plus `EN_BUCKS` readback to a Teensy pin | PSU 15 V / 1 A, bucks on with no load. Press E-stop. **Pass:** U1/U2/U3 VOUT < 0.5 V and `EN_BUCKS` < 0.4 V; everything recovers on release; J21 flips on the same press | | net `EN_BUCKS` = Q2.3 Q3.3 U1/U2/U3/U5.3, no resistor; `BUILD_PLAN.md:818-834`; #395 |
| PC-06 | Per-cell LiPo | One cell sags. 3×3.6 + 2.6 = 13.4 V trips nothing | Cell over-discharged → swelling, and a fire risk on the next charge | Balance-lead buzzer at 3.3 V/cell: audible only, no cut | 4 | v6: buzzer, and pull the pack at 14.0 V. Backlog #9 (per-cell ADC): put dividers on the tap wires only, and **never tie the balance pack− pin to board GND**, because that bypasses Q1 ([PC-09](#pc-09)). v7: cell-monitor IC | Per-cell voltage off the balance lead at rest and 60 s after a load run. **Pass:** spread < 50 mV | | `docs/improvement-backlog.md:33-66`; the only pack sense is `R2`/`R3` off `VBAT_PROTECTED` |
| PC-07 | `HARDCUT` hysteresis vs pack rebound | The hardcut drops ~15 A of load. Pack + harness IR rebound (≥0.3 V) exceeds the 0.28 V band (12.42↓ / 12.70↑), so the bucks and the Jetson re-enable, sag, cut, and repeat | Leg/hip rails and the Jetson hard power-cycle (filesystem risk), and the pack is driven deeper. wiring/README calls the comparators "latched". They are not | None in hardware. The firmware `BATT_LOW` path has to shut down first (0.54 V window) | 3 | v6: `R14` 470 k→150 k gives a ~0.9 V band, but the falling trip drops to ~12.1 V, so retune `R6`/`R7`. Or rely on graceful shutdown + SW1 off. v7: a true latch, reset by cycling SW1 | PSU → 0.2 Ω (stand-in for pack IR) → J1, ≥2 A load on U2, logic analyzer on `HARDCUT`/`EN_BUCKS`, ramp down through 12.4 V. **Pass:** one edge, and no re-enable until the PSU goes back above 12.7 V + sag | | `06_safety_chain.kicad_sch:2973` (R14); nets `HARDCUT`, `VREF_H`; `hardware/wiring/README.md:50-52` |
| PC-08 | Hardcut is not a disconnect | After a hardcut, the UBEC (no EN), `M1`, the SW1 lamp, the Teensy and the Nano keep drawing from the pack | With SW1 left ON (overnight, say), the pack runs below 3.0 V/cell | None. The Jetson is off and nothing prompts "switch off" | 3 | v6: procedure: SW1 OFF after any hardcut, plus an OLED/LED alert from the Nano. v7: the latched hardcut also gates the UBEC, or pulls Q1's gate | After a HARDCUT at 12.3 V, read the PSU current. Record mA, then hours = 10 % of 6000 mAh ÷ I | | `hardware/wiring/README.md:50-52`; `J2` has no EN pin |
| PC-09 | `BATT_NEG` ≠ `GND` (Q1 on the low-side leg) | Anything that joins pack− to board GND: the TO-220 tab (= drain) on a grounded chassis or heatsink, an `H1` standoff (H1 is `BATT_NEG`), the balance-lead − into a cell ADC, a grounded scope or charger clip on both | Q1 silently bypassed. If the XT60 − opens, the return current runs through the thin wire instead | Diode-mode J1.1↔GND asymmetry (passed 2026-08-16). That result holds only until the next part is bolted on | 3 | v6: isolated mounting, and re-run the check after every mechanical change. v7: high-side P-FET or ideal-diode controller, so pack− = GND | Diode mode, `J1`.1↔`Q1`.3. **Pass:** asymmetric (~0.5 V one way, OL the other). **Fail:** ~0 Ω both ways | | `BUILD_PLAN.md:698-701`, `:1041-1067`; `STATUS.md:204` |
| PC-10 | Inrush at SW1 close (#244) | 940 µF (`C8`+`C9`) plus the buck input ceramics charge through SW1 with no limit. Q1's soft-start does not come into it: the **body diode** carries the inrush (≈Vf·Q ≈ 0.02 J in Q1), so the #244 SOA worry is misplaced | SW1 contacts pit or weld (a welded SW1 cannot switch off). Harness-L ringing reaches up to ~2×16.8 = 33.6 V at the U3 D24V22F12 VIN (36 V max) | None | 3 | v6: precharge resistor (10–47 Ω, 2–3 W) with a bypass, or accept the risk and inspect the contacts. v7: precharge or hot-swap controller, plus a TVS on `VBAT_PROTECTED` | Scope U3 VIN at SW1 close on the pack (borrowed scope). **Pass:** peak < 30 V. Until then: inspect the SW1 contacts every 20 cycles | | bulk on `VBAT_PROTECTED` = C8, C9 only (C1–C6 sit on buck outputs); `docs/power-budget.md:123`; #244 |
| PC-11 | Trip-point numbers in docs | Docs give 13.03 / 12.56 V, which leaves out the R14/R15 loading. As built (4.98 V UBEC, 0.1794 divider): `BATT_LOW` 12.96↓ / 13.06↑, `HARDCUT` 12.42↓ / 12.70↑. The trips are ratiometric to V5_AUX: ±2 % gives ±0.25 V | A correct board "fails" the sweep, or a wrong one passes. The graceful window is 0.54 V, not 0.47 | Bench sweep, written but not run | 2 | Use these numbers. Sweep both directions and rescale by the measured V5_AUX | Sweep 13.5→12.0→13.5 V slowly and log each edge. **Pass:** within ±0.1 V of the four values above | | `pre-power-on-validation.md:314-325`; nets `VREF_G`, `VREF_H` |
| PC-12 | `U8` LM393 supply | No bypass cap at U8. UBEC ripple → chatter at the threshold | `EN_BUCKS`/`EN_JET` toggle near 12.4 V | None | 2 | v6: hand-tack 100 nF across pins 8↔4. v7: on the board | Logic analyzer on `HARDCUT` during the slow sweep. **Pass:** one clean edge | | `pre-power-on-validation.md:202` |
| PC-13 | First power-up at a 0.5 A PSU limit | **UNVERIFIED.** The PSU goes CC while C8/C9 charge and the UBEC and bucks start. VBAT sags below 12.42 → hardcut → recovers → cycles | Looks like a dead board and stresses the UBEC | PSU CC lamp | 2 | Start at 15.0 V / 0.5 A with every buck XT30 unplugged. Add bucks one at a time with the limit at 2 A | **Pass:** V5_AUX 4.9–5.1 V, `HARDCUT` < 0.4 V, PSU settles < 0.2 A (record the value) | | `pre-power-on-validation.md:376` |
| PC-14 | INA226 address straps (U9–U12) | A0/A1 are not on the board, so a module bead sets the address. Failures: two modules on one address, or the leg module with IN− untapped | `/power_rails` wrong or missing. No protection depends on it | I²C scan | 2 | v6: bead per the §1e table and label each module. v7: A0/A1 to board straps | I²C scan from the Teensy. **Pass:** exactly 0x40 0x41 0x44 0x45 | | nets `unconnected-(U9..U12-A0/A1)`; `pre-power-on-validation.md:243-252` |
| PC-15 | `U7` 74LVC125 /OE (logic board) | `OE_TX`/`OE_RX` (U7.1, U7.4) have no pull-ups. Teensy pins are hi-Z during boot and flash, so the buffers can enable | The TX buffer drives the servo bus from a floating input → garbage frames, or contention with a replying servo | None | 2 | v6: 10 k from U7.1 and U7.4 to `+3V3` (disabled by default). v7: on the board | Teensy held in bootloader, logic analyzer on `BUS_SIGNAL` for 2 s. **Pass:** idle high, no edges; U7.1/U7.4 ≥ 3 V | | logic netlist: `OE_TX` = U6.5 U7.1, `OE_RX` = U6.6 U7.4, nothing else |

**Notes.** PC-01 is analysis from the netlist, not yet a measurement. Its bench check is built so that
a defeated board fails *visibly* (Vds ≈ Vth, not ≈ 0). With the loads unplugged the current is small
either way, so read the voltage. Superseded claims elsewhere carry inline `⚠ superseded by` notes:
`order-list.md` (drain-referenced gate "still works", 5470 µF), `pre-power-on-validation.md` ("Q1
covers a slip", 5470 µF), `hardware/wiring/README.md` ("R13/R14 deleted", "comparators latched").
`R13` and `R14` are live and populated.

## Top 3 before the first pack connect

1. **PC-01:** rework the 3 gate-network ends onto `Q1`.3, then pass the 5 V reversed-input test. Until then, the XT60 key is the only reverse-polarity protection.
2. **PC-05 + PC-02:** on the bench PSU, prove the E-stop takes every buck VOUT to 0 (ENA/ENB settled), and read each module's VOUT before any servo is attached.
3. **PC-11/PC-07:** run the LVC sweep both ways with a series resistor standing in for pack IR, and know whether the hardcut latches or cycles *before* a real pack gets to 12.4 V.

## What I'd tell an interviewer

- My reverse-polarity FET passed every continuity check and still didn't protect anything. The symbol's pin 2 was labelled source, but the part's pin 2 is the drain, so the gate clamp was referenced to the wrong terminal, and a reversed pack forward-biases the zener and turns the FET *on*. I found it by reading the exported netlist against the datasheet pinout, and the fix is three rework wires.
- A single-point failure hid in my safety chain: the E-stop and the undervoltage cut both depend on the 5 V UBEC for gate bias. If the UBEC dies, the bucks re-enable. On v7 the chain is biased from the pack and the enables default off, so losing logic power means losing motor power.
- I stopped trusting documented numbers the tool didn't compute. The trip points left out their own hysteresis resistors, the inrush energy was summed over capacitors that sit behind the bucks, not on the hot-plugged rail, and the "soft-start" never carried the inrush, because the body diode does. Each row here has a bench check with a pass criterion, so every claim ends up as a measurement.

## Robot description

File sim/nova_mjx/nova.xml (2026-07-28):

<mujoco model="nova_sm3">
  <compiler angle="radian" autolimits="true"/>
  <option timestep="0.004" iterations="10" ls_iterations="10">
    <flag eulerdamp="disable"/>
  </option>

  <default>
    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
    <joint damping="0.5" armature="0.008" frictionloss="0.20"/>
    <default class="viz">
      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
    </default>
    <default class="foot">
      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
    </default>
  </default>

  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

  <worldbody>
    <light pos="0 0 3" dir="0 0 -1" directional="true"/>
    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

    <body name="trunk" pos="0 0 0.17">
      <freejoint name="root"/>
      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
      <camera name="track" mode="trackcom" pos="0 -1.3 0.6" xyaxes="1 0 0 0 0.45 1"/>
      <inertial pos="0.00000 +0.00000 0.00000" mass="2.8300" diaginertia="8.7000e-03 2.4600e-02 2.6500e-02"/>
      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

      <body name="FL_hip" pos="0.1412 0.0390 0.0380">
        <joint name="FL_haa" axis="1 0 0" range="-0.2620 0.6980" damping="0.616"/>
        <inertial pos="0.00710 +0.02000 -0.00800" mass="0.0836" diaginertia="4.0990e-05 2.1200e-05 3.2550e-05"/>
        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
        <body name="FL_upper" pos="-0.0116 0.0338 -0.0095">
          <joint name="FL_hfe" axis="0 1 0" range="-1.5010 0.8730" damping="0.643"/>
          <inertial pos="0.00000 +0.00650 -0.05070" mass="0.1219" diaginertia="7.4860e-05 6.6490e-05 2.6670e-05"/>
          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
          <body name="FL_lower" pos="0 0 -0.1069">
            <joint name="FL_kfe" axis="0 1 0" range="-1.9000 1.9000" damping="0.643"/>
            <inertial pos="-0.00050 +0.01010 -0.06560" mass="0.1110" diaginertia="1.0060e-04 9.1500e-05 2.3210e-05"/>
            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
            <body name="FL_foot" pos="0 0.0305 -0.1290">
              <inertial pos="0.00000 +0.00000 0.00000" mass="0.0039" diaginertia="2.1160e-07 5.6020e-07 5.7630e-07"/>
              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
            </body>
          </body>
        </body>
      </body>
      <body name="FR_hip" pos="0.1412 -0.0390 0.0380">
        <joint name="FR_haa" axis="1 0 0" range="-0.6980 0.2620" damping="0.616"/>
        <inertial pos="0.00710 -0.02000 -0.00800" mass="0.0836" diaginertia="4.0990e-05 2.1200e-05 3.2550e-05"/>
        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
        <body name="FR_upper" pos="-0.0116 -0.0338 -0.0095">
          <joint name="FR_hfe" axis="0 1 0" range="-1.5010 0.8730" damping="0.643"/>
          <inertial pos="0.00000 -0.00650 -0.05070" mass="0.1219" diaginertia="7.4860e-05 6.6490e-05 2.6670e-05"/>
          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
          <body name="FR_lower" pos="0 0 -0.1069">
            <joint name="FR_kfe" axis="0 1 0" range="-1.9000 1.9000" damping="0.643"/>
            <inertial pos="-0.00050 -0.01010 -0.06560" mass="0.1110" diaginertia="1.0060e-04 9.1500e-05 2.3210e-05"/>
            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
            <body name="FR_foot" pos="0 -0.0305 -0.1290">
              <inertial pos="0.00000 -0.00000 0.00000" mass="0.0039" diaginertia="2.1160e-07 5.6020e-07 5.7630e-07"/>
              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
            </body>
          </body>
        </body>
      </body>
      <body name="RL_hip" pos="-0.1412 0.0390 0.0380">
        <joint name="RL_haa" axis="1 0 0" range="-0.2620 0.6980" damping="0.616"/>
        <inertial pos="0.00710 +0.02000 -0.00800" mass="0.0836" diaginertia="4.0990e-05 2.1200e-05 3.2550e-05"/>
        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
        <body name="RL_upper" pos="0.0116 0.0338 -0.0095">
          <joint name="RL_hfe" axis="0 1 0" range="-0.8730 1.5010" damping="0.643"/>
          <inertial pos="0.00000 +0.00650 -0.05070" mass="0.1219" diaginertia="7.4860e-05 6.6490e-05 2.6670e-05"/>
          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
          <body name="RL_lower" pos="0 0 -0.1069">
            <joint name="RL_kfe" axis="0 1 0" range="-1.9000 1.9000" damping="0.643"/>
            <inertial pos="-0.00050 +0.01010 -0.06560" mass="0.1110" diaginertia="1.0060e-04 9.1500e-05 2.3210e-05"/>
            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
            <body name="RL_foot" pos="0 0.0305 -0.1290">
              <inertial pos="0.00000 +0.00000 0.00000" mass="0.0039" diaginertia="2.1160e-07 5.6020e-07 5.7630e-07"/>
              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
            </body>
          </body>
        </body>
      </body>
      <body name="RR_hip" pos="-0.1412 -0.0390 0.0380">
        <joint name="RR_haa" axis="1 0 0" range="-0.6980 0.2620" damping="0.616"/>
        <inertial pos="0.00710 -0.02000 -0.00800" mass="0.0836" diaginertia="4.0990e-05 2.1200e-05 3.2550e-05"/>
        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
        <body name="RR_upper" pos="0.0116 -0.0338 -0.0095">
          <joint name="RR_hfe" axis="0 1 0" range="-0.8730 1.5010" damping="0.643"/>
          <inertial pos="0.00000 -0.00650 -0.05070" mass="0.1219" diaginertia="7.4860e-05 6.6490e-05 2.6670e-05"/>
          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
          <body name="RR_lower" pos="0 0 -0.1069">
            <joint name="RR_kfe" axis="0 1 0" range="-1.9000 1.9000" damping="0.643"/>
            <inertial pos="-0.00050 -0.01010 -0.06560" mass="0.1110" diaginertia="1.0060e-04 9.1500e-05 2.3210e-05"/>
            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
            <body name="RR_foot" pos="0 -0.0305 -0.1290">
              <inertial pos="0.00000 -0.00000 0.00000" mass="0.0039" diaginertia="2.1160e-07 5.6020e-07 5.7630e-07"/>
              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
            </body>
          </body>
        </body>
      </body>
    </body>
  </worldbody>

  <actuator>
    <position name="FL_haa" joint="FL_haa" kp="35" kv="0" forcerange="-2.9 2.9"/>
    <position name="FL_hfe" joint="FL_hfe" kp="35" kv="0" forcerange="-1.8 1.8"/>
    <position name="FL_kfe" joint="FL_kfe" kp="35" kv="0" forcerange="-1.8 1.8"/>
    <position name="FR_haa" joint="FR_haa" kp="35" kv="0" forcerange="-2.9 2.9"/>
    <position name="FR_hfe" joint="FR_hfe" kp="35" kv="0" forcerange="-1.8 1.8"/>
    <position name="FR_kfe" joint="FR_kfe" kp="35" kv="0" forcerange="-1.8 1.8"/>
    <position name="RL_haa" joint="RL_haa" kp="35" kv="0" forcerange="-2.9 2.9"/>
    <position name="RL_hfe" joint="RL_hfe" kp="35" kv="0" forcerange="-1.8 1.8"/>
    <position name="RL_kfe" joint="RL_kfe" kp="35" kv="0" forcerange="-1.8 1.8"/>
    <position name="RR_haa" joint="RR_haa" kp="35" kv="0" forcerange="-2.9 2.9"/>
    <position name="RR_hfe" joint="RR_hfe" kp="35" kv="0" forcerange="-1.8 1.8"/>
    <position name="RR_kfe" joint="RR_kfe" kp="35" kv="0" forcerange="-1.8 1.8"/>
  </actuator>

  <sensor>
    <framequat name="trunk_quat" objtype="site" objname="imu"/>
    <gyro name="trunk_gyro" site="imu"/>
    <velocimeter name="trunk_vel" site="imu"/>
    <accelerometer name="trunk_acc" site="imu"/>
    <framepos name="trunk_pos" objtype="site" objname="imu"/>
    <jointpos name="FL_haa_p" joint="FL_haa"/>
    <jointvel name="FL_haa_v" joint="FL_haa"/>
    <jointpos name="FL_hfe_p" joint="FL_hfe"/>
    <jointvel name="FL_hfe_v" joint="FL_hfe"/>
    <jointpos name="FL_kfe_p" joint="FL_kfe"/>
    <jointvel name="FL_kfe_v" joint="FL_kfe"/>
    <jointpos name="FR_haa_p" joint="FR_haa"/>
    <jointvel name="FR_haa_v" joint="FR_haa"/>
    <jointpos name="FR_hfe_p" joint="FR_hfe"/>
    <jointvel name="FR_hfe_v" joint="FR_hfe"/>
    <jointpos name="FR_kfe_p" joint="FR_kfe"/>
    <jointvel name="FR_kfe_v" joint="FR_kfe"/>
    <jointpos name="RL_haa_p" joint="RL_haa"/>
    <jointvel name="RL_haa_v" joint="RL_haa"/>
    <jointpos name="RL_hfe_p" joint="RL_hfe"/>
    <jointvel name="RL_hfe_v" joint="RL_hfe"/>
    <jointpos name="RL_kfe_p" joint="RL_kfe"/>
    <jointvel name="RL_kfe_v" joint="RL_kfe"/>
    <jointpos name="RR_haa_p" joint="RR_haa"/>
    <jointvel name="RR_haa_v" joint="RR_haa"/>
    <jointpos name="RR_hfe_p" joint="RR_hfe"/>
    <jointvel name="RR_hfe_v" joint="RR_hfe"/>
    <jointpos name="RR_kfe_p" joint="RR_kfe"/>
    <jointvel name="RR_kfe_v" joint="RR_kfe"/>
  </sensor>

  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
</mujoco>

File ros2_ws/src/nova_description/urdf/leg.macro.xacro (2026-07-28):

<?xml version="1.0"?>
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
<robot xmlns:xacro="http://www.ros.org/wiki/xacro">

  <xacro:macro name="nova_leg" params="leg side mount_x mount_y mount_z reflect">
    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
    <joint name="${leg}_haa" type="revolute">
      <parent link="base_link"/>
      <child link="${leg}_hip"/>
      <origin xyz="${mount_x} ${mount_y} ${mount_z}" rpy="0 0 0"/>
      <axis xyz="1 0 0"/>
      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
      <limit lower="${-haa_in if reflect == 1 else -haa_out}" upper="${haa_out if reflect == 1 else haa_in}" effort="${eff_hip}" velocity="${vel_servo}"/>
    </joint>
    <link name="${leg}_hip">
      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
      <xacro:hip_inertial reflect="${reflect}"/>
    </link>

    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
    <joint name="${leg}_hfe" type="revolute">
      <parent link="${leg}_hip"/>
      <child link="${leg}_upper"/>
      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
      <origin xyz="${hip_to_upper_x if leg[0] == 'R' else -hip_to_upper_x} ${reflect*hip_to_upper_y} ${hip_to_upper_z}" rpy="0 0 0"/>
      <axis xyz="0 1 0"/>
      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
      <limit lower="${-hfe_ext_front if leg[0] == 'F' else -hfe_ext}" upper="${hfe_fold}" effort="${eff_leg}" velocity="${vel_servo}"/>
    </joint>
    <link name="${leg}_upper">
      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
      <xacro:upper_inertial reflect="${reflect}"/>
    </link>

    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
    <joint name="${leg}_kfe" type="revolute">
      <parent link="${leg}_upper"/>
      <child link="${leg}_lower"/>
      <origin xyz="${upper_to_lower_x} ${reflect*upper_to_lower_y} ${upper_to_lower_z}" rpy="0 0 0"/>
      <axis xyz="0 1 0"/>
      <limit lower="${-kfe_range}" upper="${kfe_range}" effort="${eff_leg}" velocity="${vel_servo}"/>
    </joint>
    <link name="${leg}_lower">
      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
      <xacro:lower_inertial reflect="${reflect}"/>
    </link>

    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
    <joint name="${leg}_foot_joint" type="fixed">
      <parent link="${leg}_lower"/>
      <child link="${leg}_foot"/>
      <origin xyz="${lower_to_foot_x} ${reflect*lower_to_foot_y} ${lower_to_foot_z}" rpy="0 0 0"/>
    </joint>
    <link name="${leg}_foot">
      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
      <xacro:foot_inertial reflect="${reflect}"/>
    </link>

  </xacro:macro>
</robot>

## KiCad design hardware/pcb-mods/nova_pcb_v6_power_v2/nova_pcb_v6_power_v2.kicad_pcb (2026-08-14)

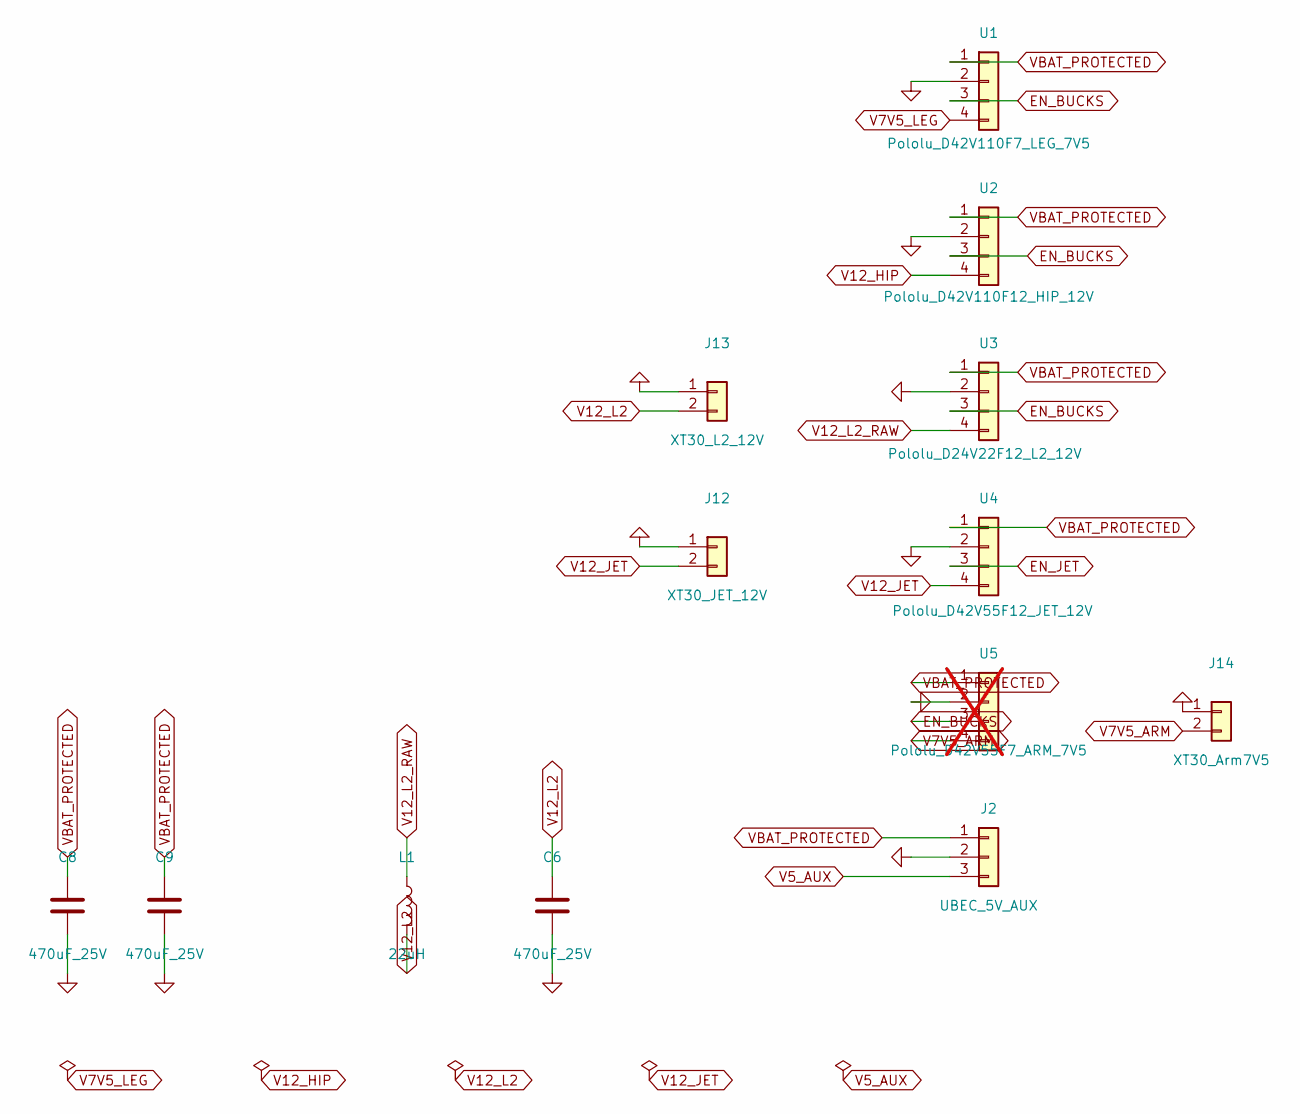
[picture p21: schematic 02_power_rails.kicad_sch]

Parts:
C6, C8, C9: 470uF_25V; CP_Radial_D10.0mm_P5.00mm; MPN UPW1E471MPD; DigiKey 493-1826-ND
J2: UBEC_5V_AUX; PinHeader_1x03_P2.54mm_Vertical; MPN PRPC040SAAN-RC; DigiKey S1011EC-40-ND
J12: XT30_JET_12V; AMASS_XT30U-M_1x02_P5.0mm_Vertical; MPN XT30U-M
J13: XT30_L2_12V; AMASS_XT30U-M_1x02_P5.0mm_Vertical; MPN XT30U-M
J14: XT30_Arm7V5; AMASS_XT30U-M_1x02_P5.0mm_Vertical; MPN XT30U-M
L1: 22uH; L_12x12mm_H8mm; MPN SRR1260-220M; DigiKey SRR1260-220MCT-ND
U1: Pololu_D42V110F7_LEG_7V5; Buck_Offboard_Terminal_2xXT30; MPN D42V110F7
U2: Pololu_D42V110F12_HIP_12V; Buck_Offboard_Terminal_2xXT30; MPN D42V110F12
U3: Pololu_D24V22F12_L2_12V; Buck_Offboard_Terminal_2xXT30; MPN D24V22F12
U4: Pololu_D42V55F12_JET_12V; Buck_Offboard_Terminal_2xXT30; MPN D42V55F12
U5: Pololu_D42V55F7_ARM_7V5; Buck_Offboard_Terminal_2xXT30; MPN D42V55F7; not fitted

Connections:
EN_BUCKS: U1.3, U2.3, U3.3, U5.3; also elsewhere on the board
EN_JET: U4.3; also elsewhere on the board
GND: C6.2, C8.2, C9.2, J2.2, J12.1, J13.1, J14.1, U1.2, U2.2, U3.2, U4.2, U5.2; also elsewhere on the board
V5_AUX: J2.3; also elsewhere on the board
V7V5_ARM: J14.2, U5.4
V7V5_LEG: U1.4; also elsewhere on the board
V12_HIP: U2.4; also elsewhere on the board
V12_JET: J12.2, U4.4
V12_L2: C6.1, J13.2, L1.2
V12_L2_RAW: L1.1, U3.4
VBAT_PROTECTED: C8.1, C9.1, J2.1, U1.1, U2.1, U3.1, U4.1, U5.1; also elsewhere on the board

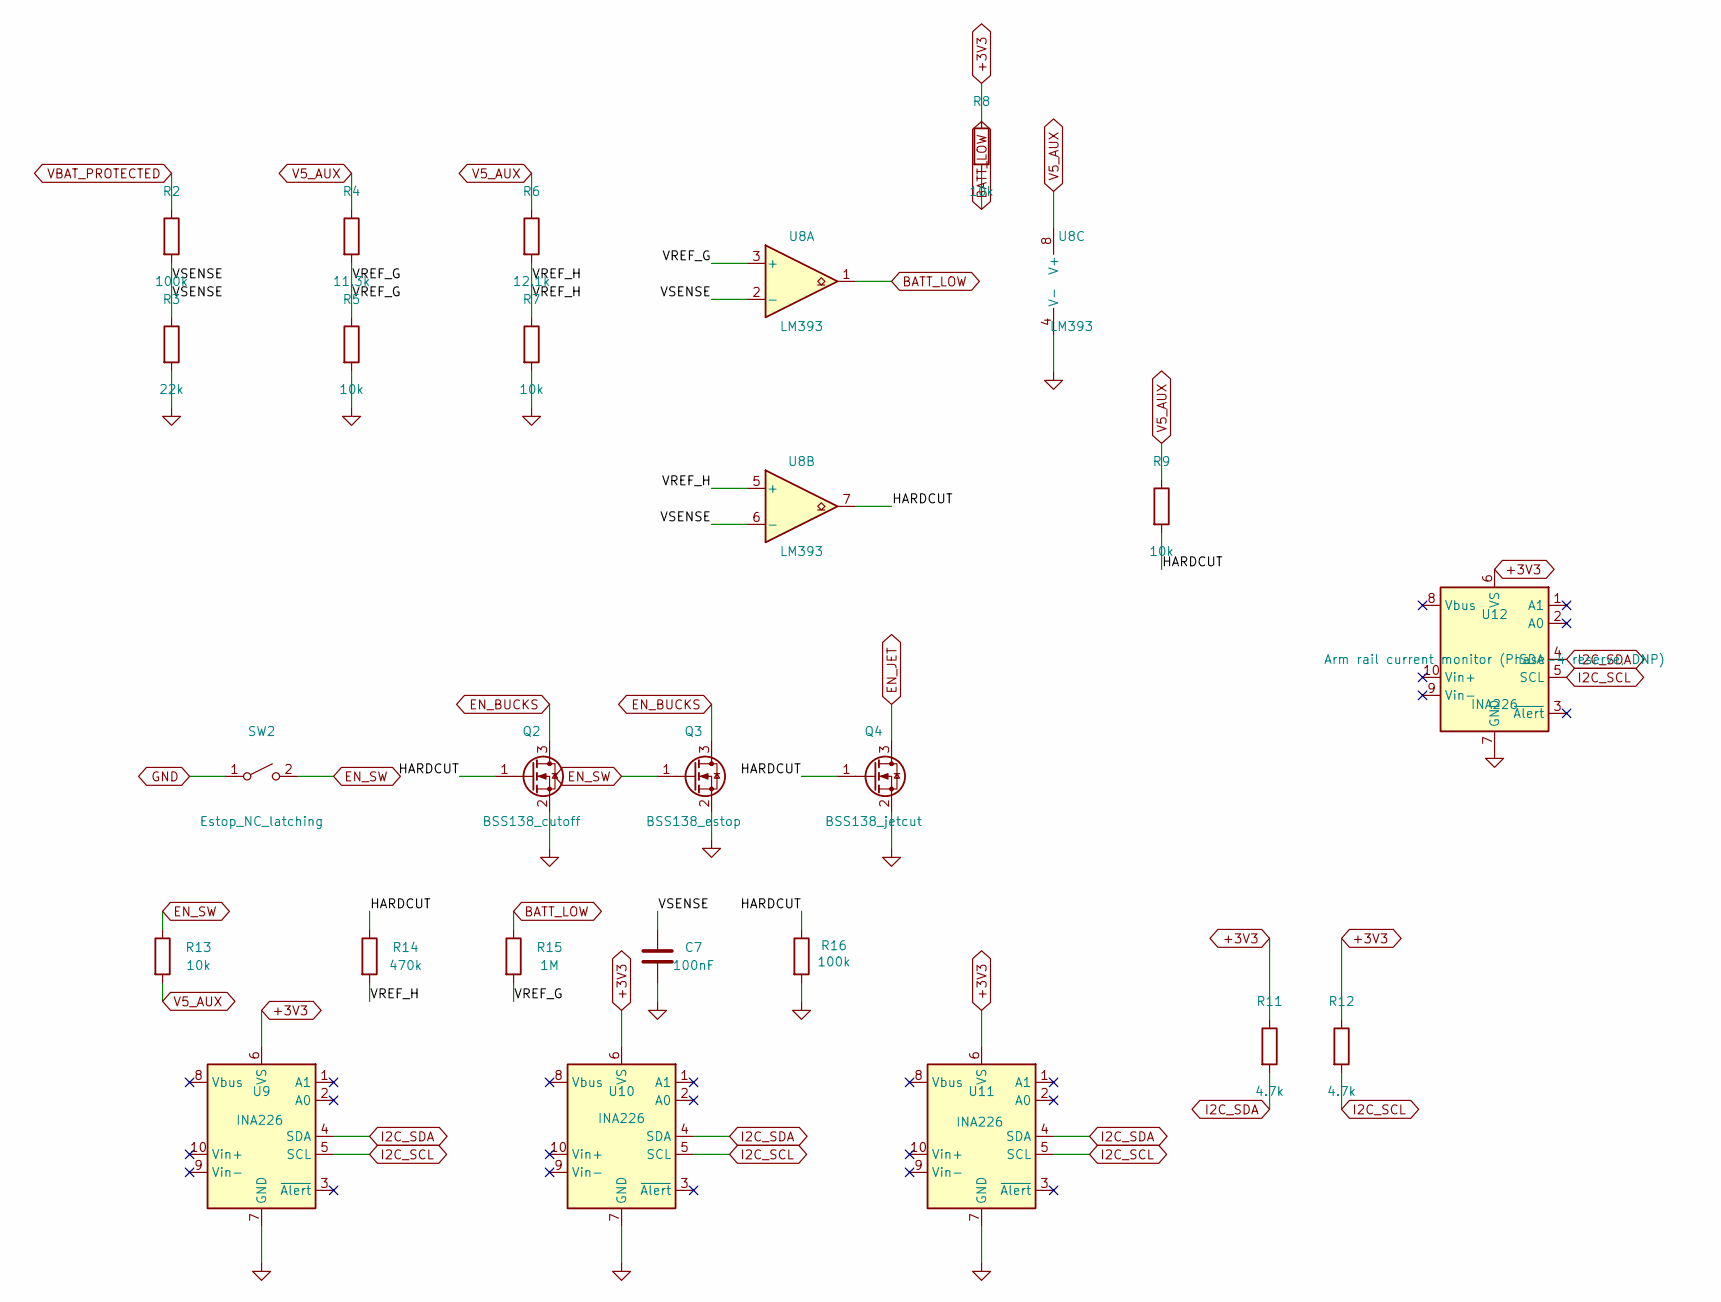
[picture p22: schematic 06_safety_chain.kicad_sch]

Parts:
C7: 100nF; C_0603_1608Metric; MPN CC0603KRX7R9BB104; DigiKey 311-1344-1-ND
Q2: BSS138_cutoff; SOT-23; MPN BSS138; DigiKey BSS138CT-ND
Q3: BSS138_estop; SOT-23; MPN BSS138; DigiKey BSS138CT-ND
Q4: BSS138_jetcut; SOT-23; MPN BSS138; DigiKey BSS138CT-ND
R2, R16: 100k; R_0603_1608Metric; MPN RC0603FR-07100KL; DigiKey 311-100KHRCT-ND
R3: 22k; R_0603_1608Metric; MPN RC0603FR-0722KL; DigiKey 311-22.0KHRCT-ND
R4: 11.3k; R_0603_1608Metric; MPN RC0603FR-0711K3L; DigiKey 311-11.3KHRCT-ND
R5, R7, R8, R9, R13: 10k; R_0603_1608Metric; MPN RC0603FR-0710KL; DigiKey 311-10.0KHRCT-ND
R6: 12.1k; R_0603_1608Metric; MPN RC0603FR-0712K1L; DigiKey 311-12.1KHRCT-ND
R11, R12: 4.7k; R_0603_1608Metric; MPN RC0603FR-074K7L; DigiKey 311-4.70KHRCT-ND
R14: 470k; R_0603_1608Metric; MPN CRCW0603470KFKEA; DigiKey 541-470KHCT-ND
R15: 1M; R_0603_1608Metric; MPN RC0603FR-071ML; DigiKey 311-1.00MHRCT-ND
SW2: Estop_NC_latching; TerminalBlock_Philmore_TB132_1x02_P5.00mm_Horizontal; MPN KF301-5.0-2P
U8: LM393; SOIC-8_3.9x4.9mm_P1.27mm; MPN LM393DR; DigiKey 296-1015-1-ND
U9, U10, U11, U12: INA226; INA226_Module_Breakout; MPN INA226-20A-R002-MODULE

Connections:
+3V3: R8.1, R11.1, R12.1, U9.6 (VS), U10.6 (VS), U11.6 (VS), U12.6 (VS); also elsewhere on the board
/06 Safety Chain/HARDCUT: Q2.1 (G), Q4.1 (G), R9.2, R14.1, R16.1, U8.7
/06 Safety Chain/VREF_G: R4.2, R5.1, R15.2, U8.3 (+)
/06 Safety Chain/VREF_H: R6.2, R7.1, R14.2, U8.5 (+)
/06 Safety Chain/VSENSE: C7.1, R2.2, R3.1, U8.2 (-), U8.6 (-)
BATT_LOW: R8.2, R15.1, U8.1; also elsewhere on the board
EN_BUCKS: Q2.3 (D), Q3.3 (D); also elsewhere on the board
EN_JET: Q4.3 (D); also elsewhere on the board
EN_SW: Q3.1 (G), R13.1, SW2.2 (B)
GND: C7.2, Q2.2 (S), Q3.2 (S), Q4.2 (S), R3.2, R5.2, R7.2, R16.2, SW2.1 (A), U8.4 (V-), U9.7 (GND), U10.7 (GND), U11.7 (GND), U12.7 (GND); also elsewhere on the board
I2C_SCL: R12.2, U9.5 (SCL), U10.5 (SCL), U11.5 (SCL), U12.5 (SCL); also elsewhere on the board
I2C_SDA: R11.2, U9.4 (SDA), U10.4 (SDA), U11.4 (SDA), U12.4 (SDA); also elsewhere on the board
V5_AUX: R4.1, R6.1, R9.1, R13.2, U8.8 (V+); also elsewhere on the board
VBAT_PROTECTED: R2.1; also elsewhere on the board

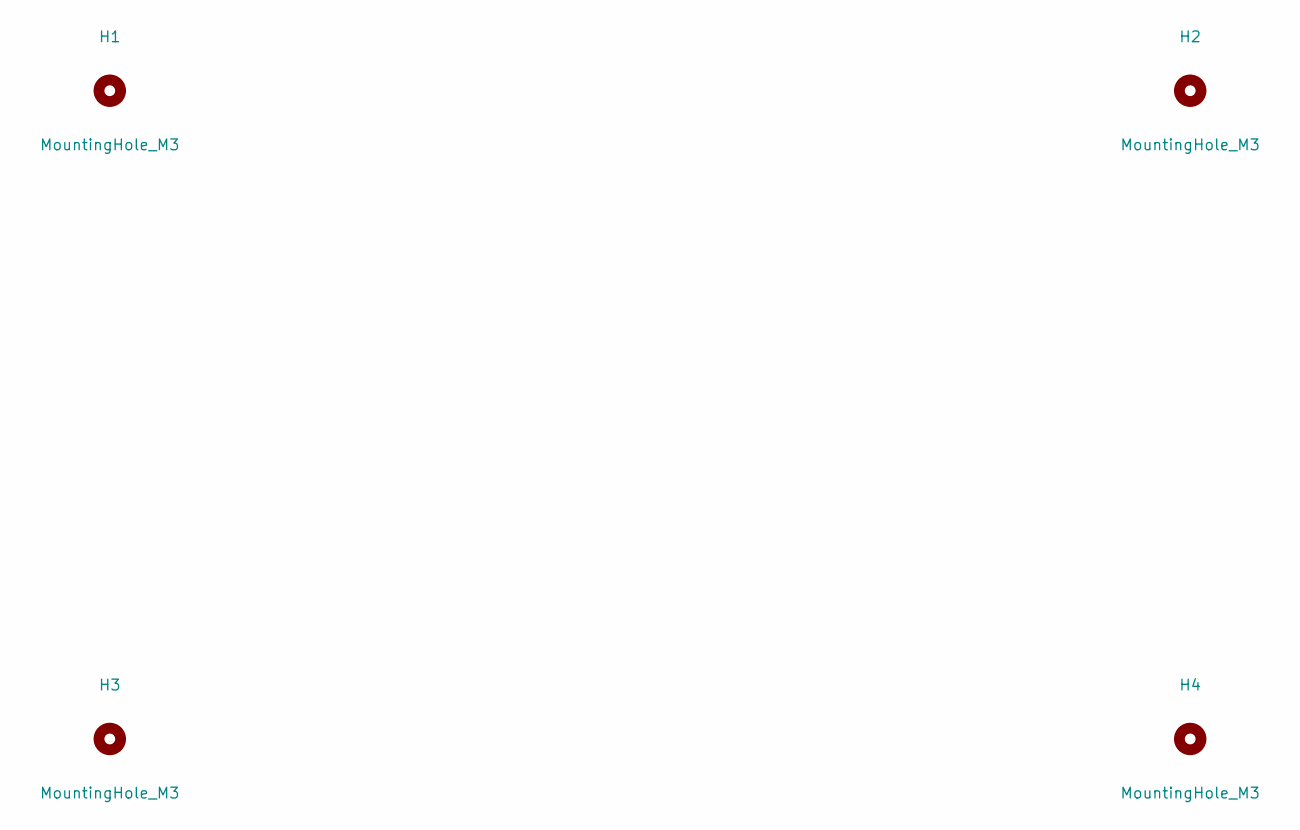
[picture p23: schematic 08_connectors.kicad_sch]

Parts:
H1, H2, H3, H4: MountingHole_M3; MountingHole_3.2mm_M3

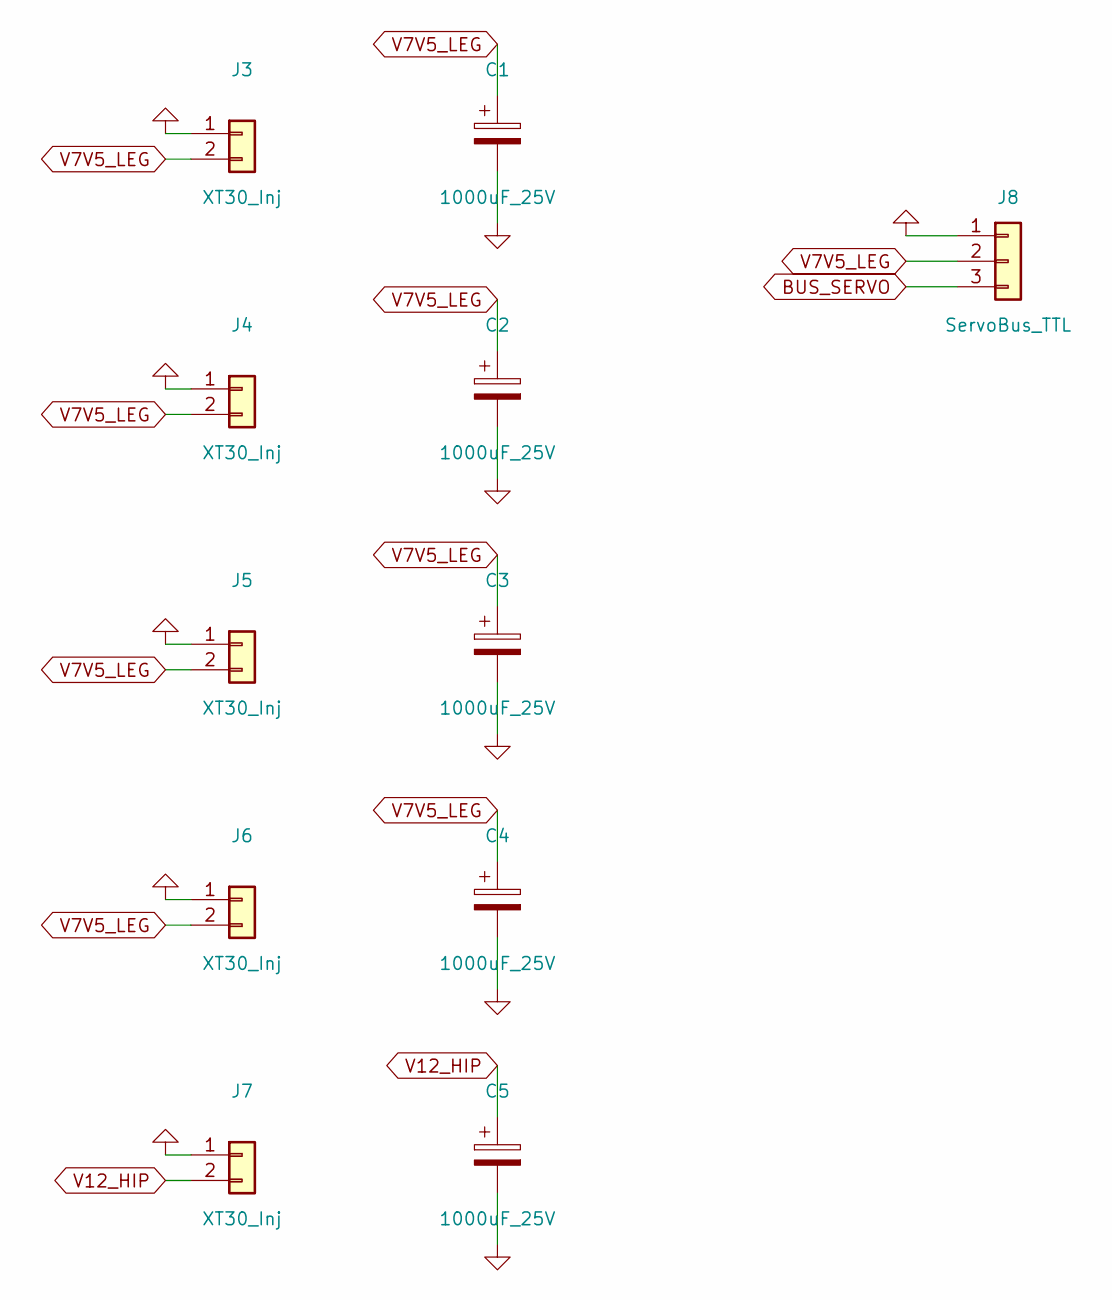
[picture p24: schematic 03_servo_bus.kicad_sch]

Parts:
C1, C2, C3, C4, C5: 1000uF_25V; CP_Radial_D12.5mm_P5.00mm; MPN FymuSing-1000uF-25V
J3, J4, J5, J6, J7: XT30_Inj; AMASS_XT30U-M_1x02_P5.0mm_Vertical; MPN XT30U-M
J8: ServoBus_TTL; JST_XH_B3B-XH-A_1x03_P2.50mm_Vertical; MPN B3B-XH-A; DigiKey 455-2248-ND

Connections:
BUS_SERVO: J8.3; also elsewhere on the board
GND: C1.2, C2.2, C3.2, C4.2, C5.2, J3.1, J4.1, J5.1, J6.1, J7.1, J8.1; also elsewhere on the board
V7V5_LEG: C1.1, C2.1, C3.1, C4.1, J3.2, J4.2, J5.2, J6.2, J8.2; also elsewhere on the board
V12_HIP: C5.1, J7.2; also elsewhere on the board

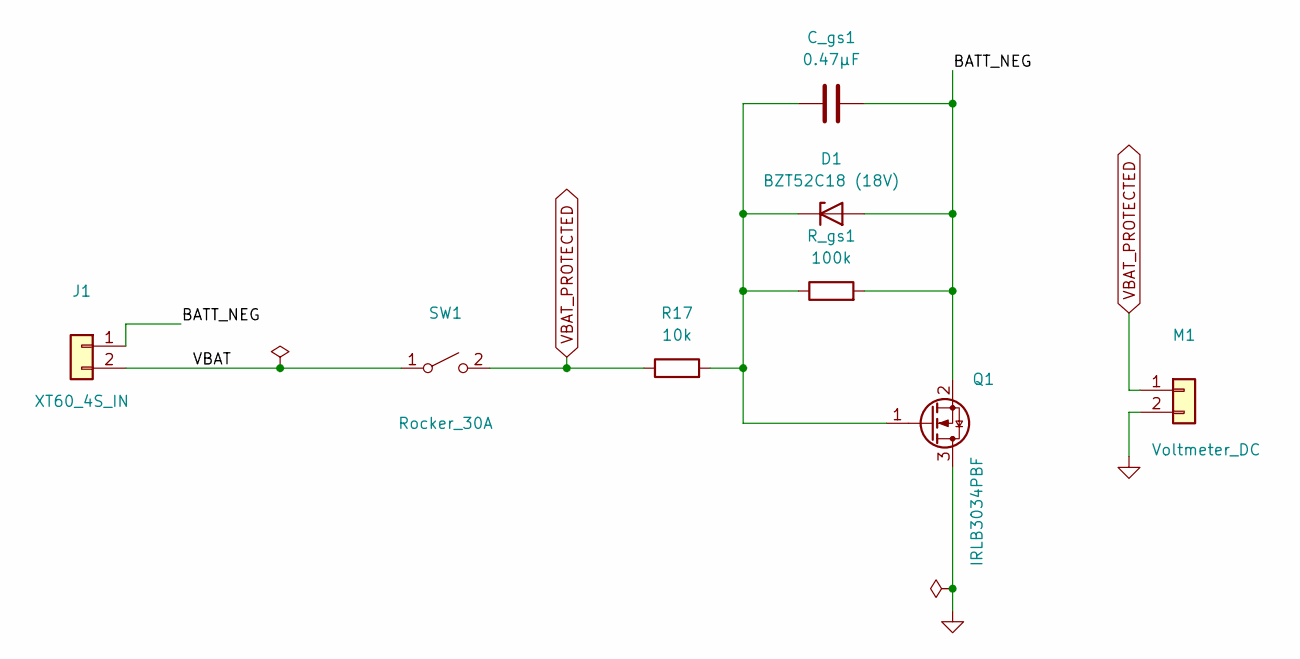
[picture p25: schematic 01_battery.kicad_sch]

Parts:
C_gs1: 0.47μF; C_0603_1608Metric
D1: BZT52C18 (18V); D_SOD-123F
J1: XT60_4S_IN; AMASS_XT60-M_1x02_P7.20mm_Vertical; MPN XT60H-M
M1: Voltmeter_DC; PinHeader_1x02_P2.54mm_Vertical; MPN PRPC040SAAN-RC; DigiKey S1011EC-40-ND
Q1: IRLB3034PBF; TO-220-3_Vertical; MPN IRLB3034PBF
R17: 10k; R_0603_1608Metric
R_gs1: 100k; R_0603_1608Metric
SW1: Rocker_30A; TerminalBlock_Philmore_TB132_1x02_P5.00mm_Horizontal; MPN KF301-5.0-2P

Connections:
/01 Battery Input + Reverse Protection/BATT_NEG: C_gs1.2, D1.2 (A), J1.1, Q1.2 (S), R_gs1.2
/01 Battery Input + Reverse Protection/VBAT: J1.2, SW1.1 (A)
GND: M1.2, Q1.3 (D); also elsewhere on the board
unnamed: C_gs1.1, D1.1 (K), Q1.1 (G), R17.2, R_gs1.1
VBAT_PROTECTED: M1.1, R17.1, SW1.2 (B); also elsewhere on the board

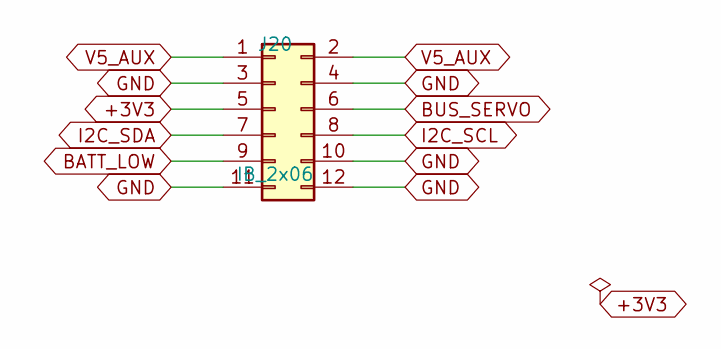
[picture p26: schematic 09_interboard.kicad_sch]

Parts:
J20: IB_2x06; IDC-Header_2x06_P2.54mm_Vertical; MPN BHR-12-VUA; DigiKey 2057-BHR-12-VUA-ND

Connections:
+3V3: J20.5; also elsewhere on the board
BATT_LOW: J20.9; also elsewhere on the board
BUS_SERVO: J20.6; also elsewhere on the board
GND: J20.3, J20.4, J20.10, J20.11, J20.12; also elsewhere on the board
I2C_SCL: J20.8; also elsewhere on the board
I2C_SDA: J20.7; also elsewhere on the board
V5_AUX: J20.1, J20.2; also elsewhere on the board

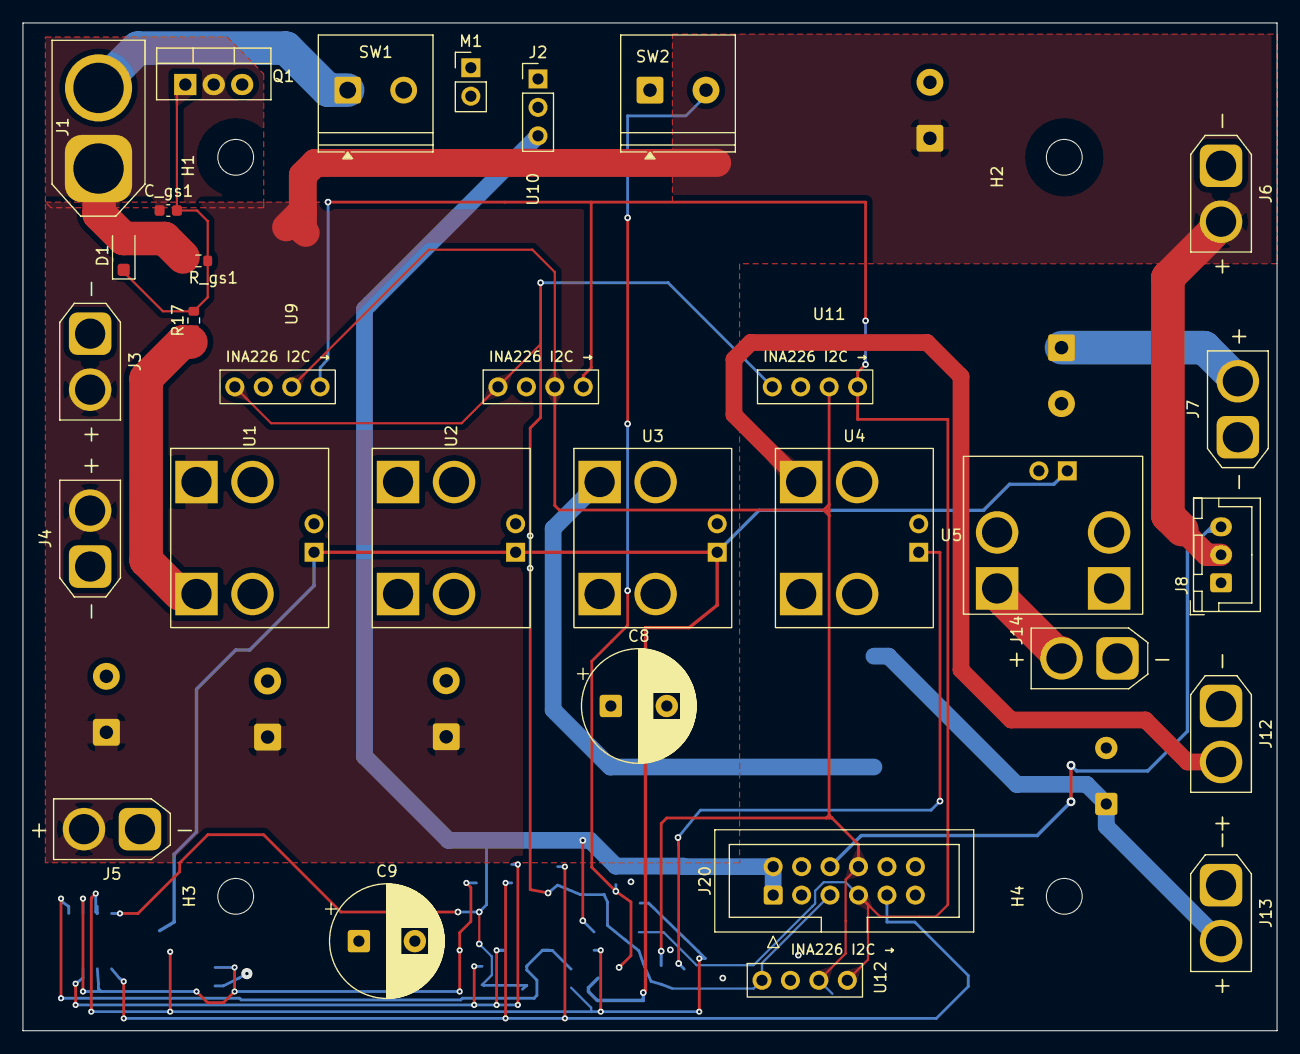
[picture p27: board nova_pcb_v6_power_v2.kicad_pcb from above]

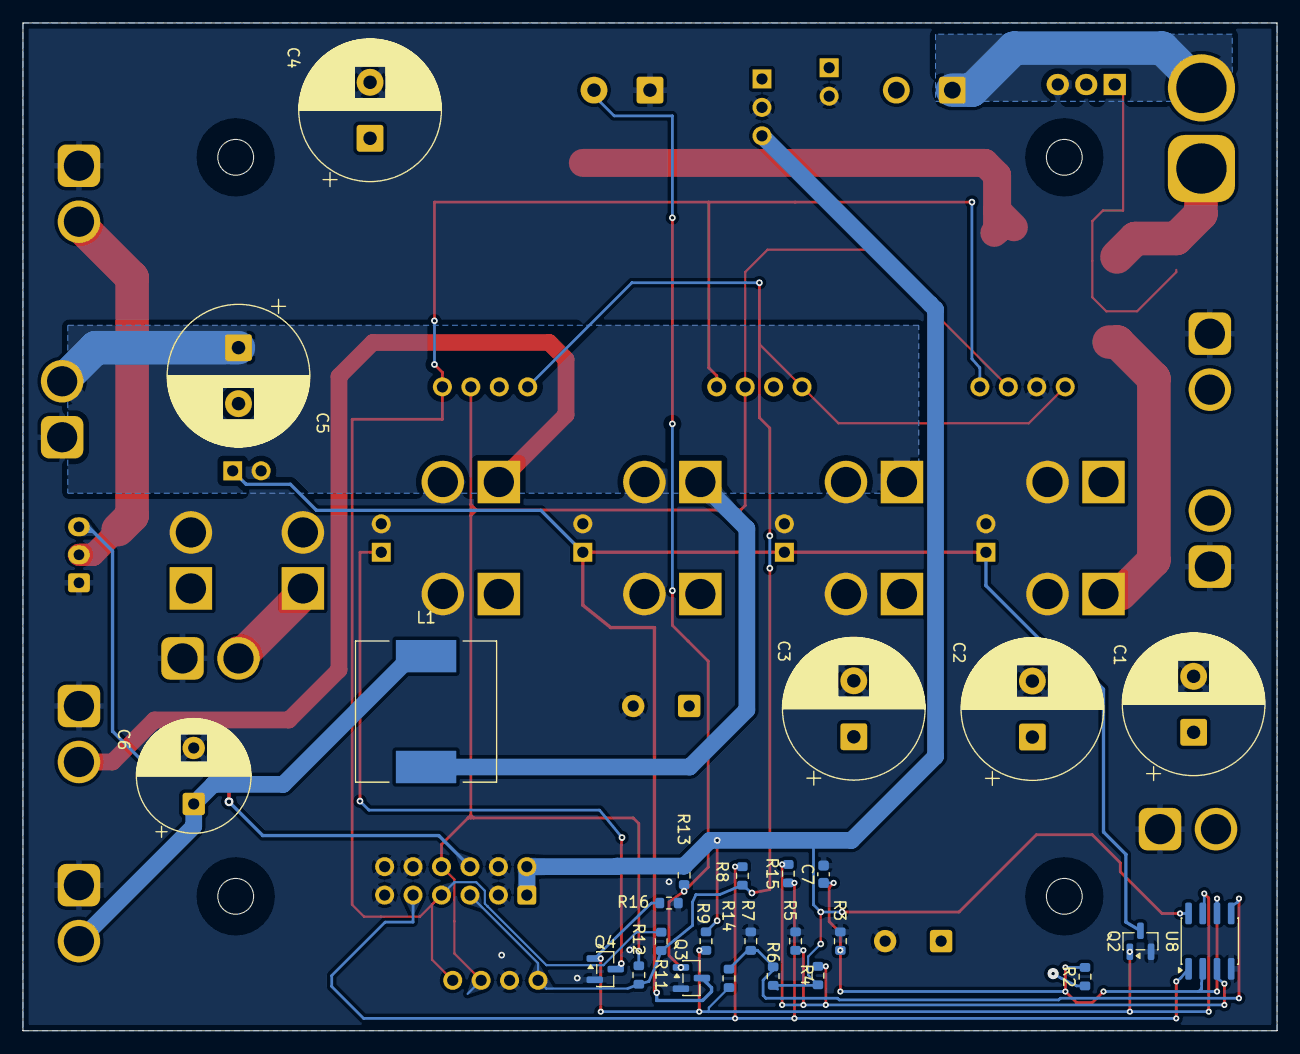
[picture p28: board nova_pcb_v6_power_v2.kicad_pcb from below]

Board: 4 copper layers, 112.0 x 90.0 mm, 61 parts (26 on the bottom side), 24 nets.

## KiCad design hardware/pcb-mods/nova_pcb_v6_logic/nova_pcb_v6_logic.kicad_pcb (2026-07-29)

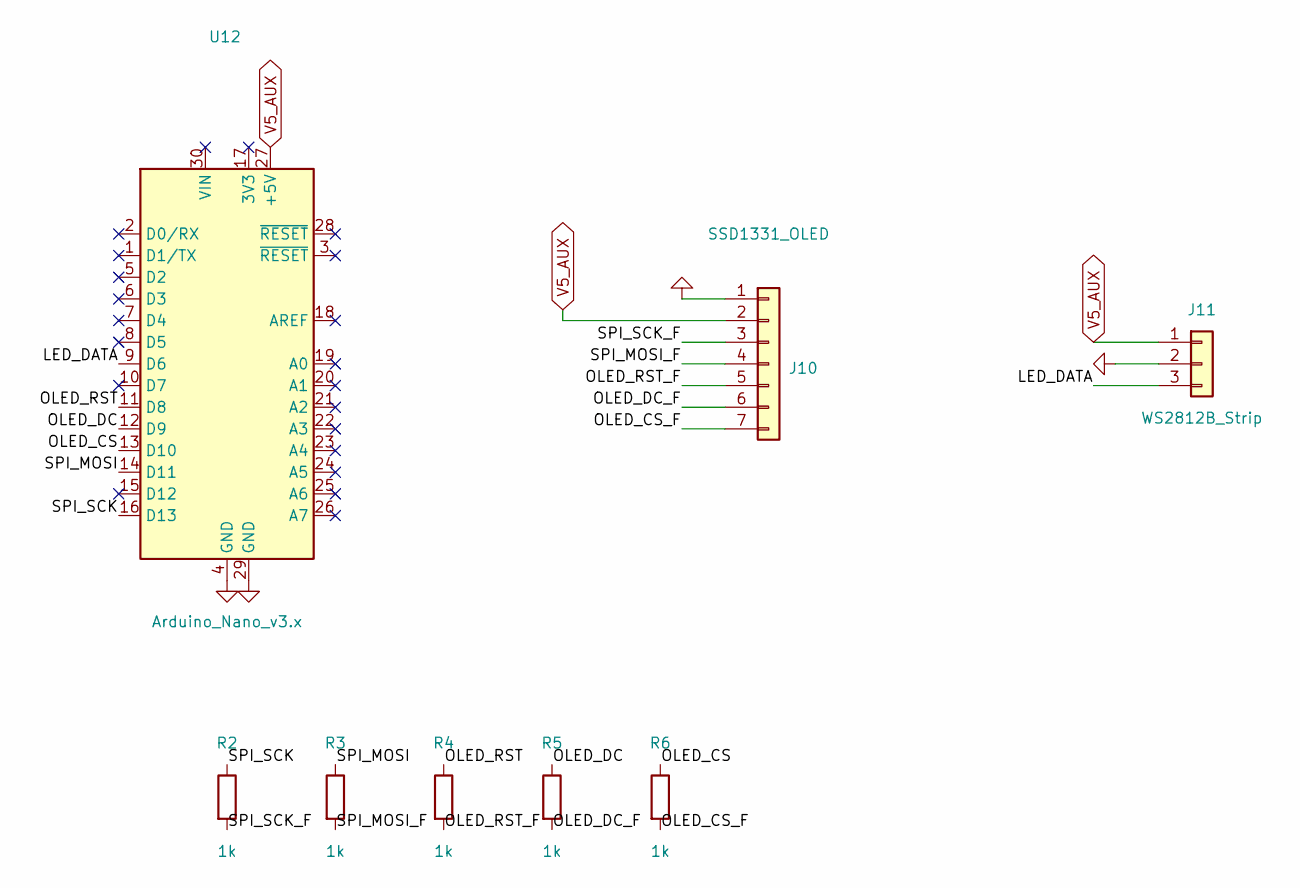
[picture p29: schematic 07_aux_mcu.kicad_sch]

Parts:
J10: SSD1331_OLED; PinHeader_1x07_P2.54mm_Vertical
J11: WS2812B_Strip; JST_XH_B3B-XH-A_1x03_P2.50mm_Vertical
R2, R3, R4, R5, R6: 1k; R_0603_1608Metric
U12: Arduino_Nano_v3.x; Arduino_Nano

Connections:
/07 Aux MCU + Peripherals/LED_DATA: J11.3, U12.9 (D6)
/07 Aux MCU + Peripherals/OLED_CS: R6.1, U12.13 (D10)
/07 Aux MCU + Peripherals/OLED_CS_F: J10.7, R6.2
/07 Aux MCU + Peripherals/OLED_DC: R5.1, U12.12 (D9)
/07 Aux MCU + Peripherals/OLED_DC_F: J10.6, R5.2
/07 Aux MCU + Peripherals/OLED_RST: R4.1, U12.11 (D8)
/07 Aux MCU + Peripherals/OLED_RST_F: J10.5, R4.2
/07 Aux MCU + Peripherals/SPI_MOSI: R3.1, U12.14 (D11)
/07 Aux MCU + Peripherals/SPI_MOSI_F: J10.4, R3.2
/07 Aux MCU + Peripherals/SPI_SCK: R2.1, U12.16 (D13)
/07 Aux MCU + Peripherals/SPI_SCK_F: J10.3, R2.2
GND: J10.1, J11.2, U12.4 (GND), U12.29 (GND); also elsewhere on the board
V5_AUX: J10.2, J11.1, U12.27 (+5V); also elsewhere on the board

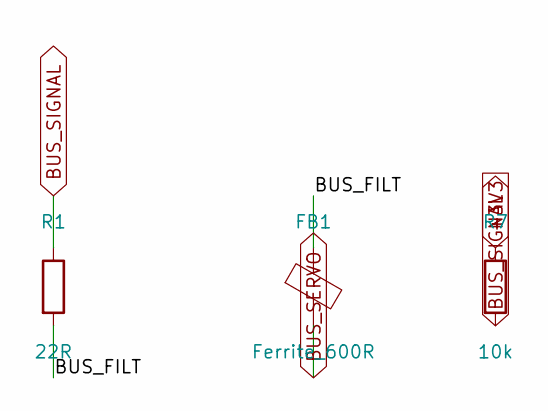
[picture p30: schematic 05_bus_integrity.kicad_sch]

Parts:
FB1: Ferrite_600R; L_0603_1608Metric
R1: 22R; R_0603_1608Metric
R7: 10k; R_0603_1608Metric

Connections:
+3V3: R7.1; also elsewhere on the board
/05 Bus Integrity/BUS_FILT: FB1.1, R1.2
BUS_SERVO: FB1.2; also elsewhere on the board
BUS_SIGNAL: R1.1, R7.2; also elsewhere on the board

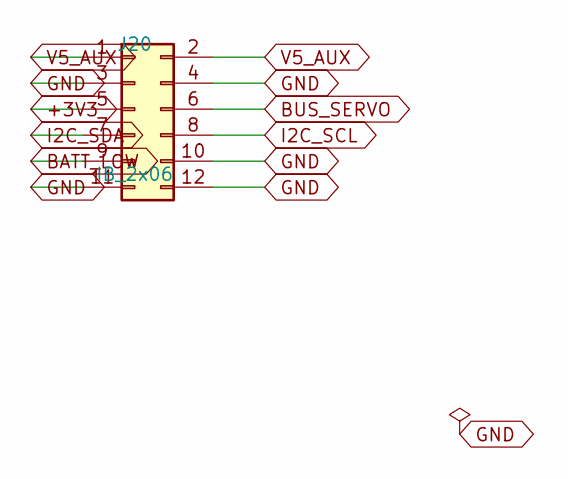
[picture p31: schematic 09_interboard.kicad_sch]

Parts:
J20: IB_2x06; IDC-Header_2x06_P2.54mm_Vertical

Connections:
+3V3: J20.5; also elsewhere on the board
BATT_LOW: J20.9; also elsewhere on the board
BUS_SERVO: J20.6; also elsewhere on the board
GND: J20.3, J20.4, J20.10, J20.11, J20.12; also elsewhere on the board
I2C_SCL: J20.8; also elsewhere on the board
I2C_SDA: J20.7; also elsewhere on the board
V5_AUX: J20.1, J20.2; also elsewhere on the board


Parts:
H1, H2, H3, H4: MountingHole_M3; MountingHole_3.2mm_M3

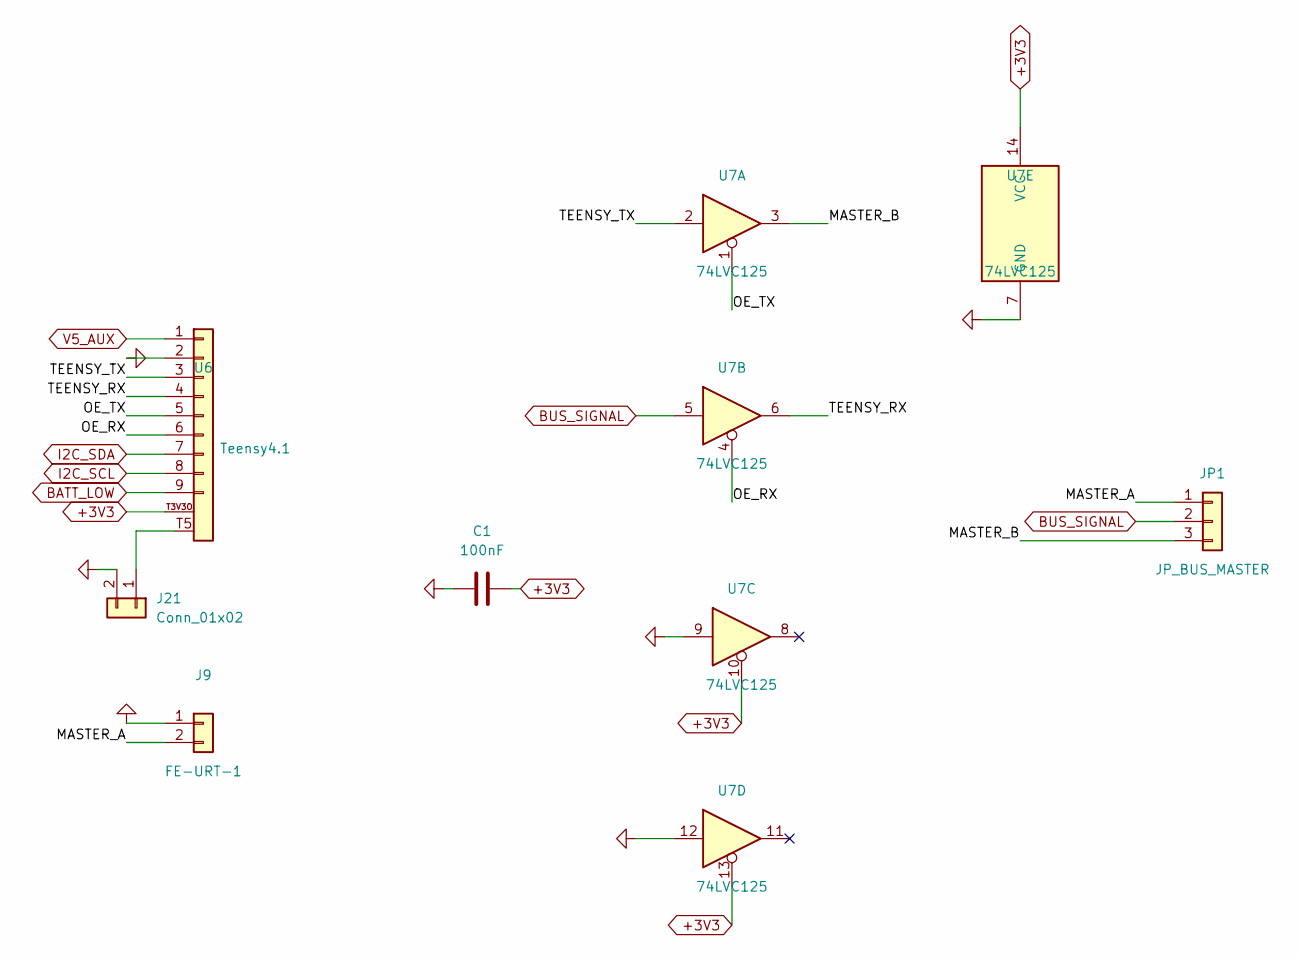
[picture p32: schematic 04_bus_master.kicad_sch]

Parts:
C1: 100nF; C_0603_1608Metric
J9: FE-URT-1; PinHeader_1x02_P2.54mm_Vertical
J21: Conn_01x02; PinHeader_1x02_P2.54mm_Vertical
JP1: JP_BUS_MASTER; PinHeader_1x03_P2.54mm_Vertical
U6: Teensy4.1; Teensy_4.1
U7: 74LVC125; SOIC-14_3.9x8.7mm_P1.27mm

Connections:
+3V3: C1.2, U6.T3V3O (3V3), U7.10, U7.13, U7.14 (VCC); also elsewhere on the board
/04 Bus Master (Pattern B)/MASTER_A: J9.2, JP1.1
/04 Bus Master (Pattern B)/MASTER_B: JP1.3, U7.3
/04 Bus Master (Pattern B)/OE_RX: U6.6, U7.4
/04 Bus Master (Pattern B)/OE_TX: U6.5, U7.1
/04 Bus Master (Pattern B)/TEENSY_RX: U6.4, U7.6
/04 Bus Master (Pattern B)/TEENSY_TX: U6.3, U7.2
BATT_LOW: U6.9; also elsewhere on the board
BUS_SIGNAL: JP1.2, U7.5; also elsewhere on the board
GND: C1.1, J9.1, J21.2, U6.2, U7.7 (GND), U7.9, U7.12; also elsewhere on the board
I2C_SCL: U6.8; also elsewhere on the board
I2C_SDA: U6.7; also elsewhere on the board
unnamed: J21.1, U6.T5
V5_AUX: U6.1; also elsewhere on the board



Board: 4 copper layers, 84.0 x 78.0 mm, 22 parts (3 on the bottom side), 27 nets.

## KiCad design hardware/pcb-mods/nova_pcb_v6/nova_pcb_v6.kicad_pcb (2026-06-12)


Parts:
J10: SSD1331_OLED; PinHeader_1x07_P2.54mm_Vertical
J11: WS2812B_Strip; JST_XH_B3B-XH-A_1x03_P2.50mm_Vertical
U12: Arduino_Nano_v3.x; Arduino_Nano

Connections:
/07 Aux MCU + Peripherals/LED_DATA: J11.3, U12.9 (D6)
/07 Aux MCU + Peripherals/NANO_3V3: J10.2, U12.17 (3V3)
/07 Aux MCU + Peripherals/OLED_CS: J10.5, U12.13 (D10)
/07 Aux MCU + Peripherals/OLED_DC: J10.6, U12.12 (D9)
/07 Aux MCU + Peripherals/OLED_RST: J10.7, U12.11 (D8)
/07 Aux MCU + Peripherals/SPI_MOSI: J10.4, U12.14 (D11)
/07 Aux MCU + Peripherals/SPI_SCK: J10.3, U12.16 (D13)
GND: J10.1, J11.2, U12.4 (GND), U12.29 (GND); also elsewhere on the board
V5_AUX: J11.1; also elsewhere on the board


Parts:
C6: 470uF_25V; CP_Radial_D10.0mm_P5.00mm
J2: UBEC_5V_AUX; PinHeader_1x03_P2.54mm_Vertical
J12: XT30_JET_12V; AMASS_XT30U-M_1x02_P5.0mm_Vertical
J13: XT30_L2_12V; AMASS_XT30U-M_1x02_P5.0mm_Vertical
L1: 22uH; L_12x12mm_H8mm
U1: Pololu_D42V110F7_LEG_7V5; Pololu_D42V110Fx
U2: Pololu_D42V110F12_HIP_12V; Pololu_D42V110Fx
U3: Pololu_D24V22F12_L2_12V; Pololu_D24V22Fx
U4: Pololu_D42V55F12_JET_12V; Pololu_D42V55Fx
U5: Pololu_D42V55F7_ARM_7V5; Pololu_D42V55Fx; not fitted

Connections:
EN_BUCKS: U1.3, U2.3, U3.3; also elsewhere on the board
GND: C6.2, J2.2, J12.2, J13.2, U1.2, U2.2, U3.2, U4.2, U5.2; also elsewhere on the board
V5_AUX: J2.3; also elsewhere on the board
V7V5_ARM: U5.4
V7V5_LEG_RAW: U1.4; also elsewhere on the board
V12_HIP_RAW: U2.4; also elsewhere on the board
V12_JET: J12.1; also elsewhere on the board
V12_JET_RAW: U4.4; also elsewhere on the board
V12_L2: C6.1, J13.1, L1.2
V12_L2_RAW: L1.1, U3.4
VBAT_PROTECTED: J2.1, U1.1, U2.1, U3.1, U4.1, U4.3, U5.1, U5.3; also elsewhere on the board


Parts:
Q2: BSS138_cutoff; SOT-23
R2, R3, R4, R5, R6, R7, R8, R9, R10, R11, R12: DNP_tune; R_0603_1608Metric; not fitted
SW2: Estop_NC_latching; TerminalBlock_Philmore_TB132_1x02_P5.00mm_Horizontal
U8: LM393; SOIC-8_3.9x4.9mm_P1.27mm
U9, U10, U11: INA226; INA226_Module_Breakout

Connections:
+3V3: R8.1, R11.1, R12.1, U9.6 (VS), U10.2 (A0), U10.6 (VS), U11.1 (A1), U11.6 (VS); also elsewhere on the board
/06 Safety Chain/HARDCUT: Q2.1 (G), R9.2, U8.7
/06 Safety Chain/VREF_G: R4.2, R5.1, U8.3 (+)
/06 Safety Chain/VREF_H: R6.2, R7.1, U8.5 (+)
/06 Safety Chain/VSENSE: R2.2, R3.1, U8.2 (-), U8.6 (-)
BATT_LOW: R8.2, U8.1; also elsewhere on the board
EN_BUCKS: Q2.3 (D), R10.1, SW2.2 (B); also elsewhere on the board
GND: Q2.2 (S), R3.2, R5.2, R7.2, R10.2, U8.4 (V-), U9.1 (A1), U9.2 (A0), U9.7 (GND), U10.1 (A1), U10.7 (GND), U11.2 (A0), U11.7 (GND); also elsewhere on the board
I2C_SCL: R12.2, U9.5 (SCL), U10.5 (SCL), U11.5 (SCL); also elsewhere on the board
I2C_SDA: R11.2, U9.4 (SDA), U10.4 (SDA), U11.4 (SDA); also elsewhere on the board
V5_AUX: R4.1, R6.1, R9.1, SW2.1 (A), U8.8 (V+); also elsewhere on the board
V7V5_LEG: U9.8 (Vbus), U9.9 (Vin-); also elsewhere on the board
V7V5_LEG_RAW: U9.10 (Vin+); also elsewhere on the board
V12_HIP: U10.8 (Vbus), U10.9 (Vin-); also elsewhere on the board
V12_HIP_RAW: U10.10 (Vin+); also elsewhere on the board
V12_JET: U11.8 (Vbus), U11.9 (Vin-); also elsewhere on the board
V12_JET_RAW: U11.10 (Vin+); also elsewhere on the board
VBAT_PROTECTED: R2.1; also elsewhere on the board


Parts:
FB1: FB_DNP; L_0603_1608Metric; not fitted
R1: 22R_DNP; R_0603_1608Metric; not fitted

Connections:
/05 Bus Integrity/BUS_FILT: FB1.1, R1.2
BUS_SERVO: FB1.2; also elsewhere on the board
BUS_SIGNAL: R1.1; also elsewhere on the board


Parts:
H1, H2, H3, H4: MountingHole_M3; MountingHole_3.2mm_M3


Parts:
C1, C2, C3, C4, C5: 1000uF_25V; CP_Radial_D12.5mm_P5.00mm
J3, J4, J5, J6, J7: XT30_Inj; AMASS_XT30U-M_1x02_P5.0mm_Vertical
J8: ServoBus_TTL; JST_XH_B3B-XH-A_1x03_P2.50mm_Vertical

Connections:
BUS_SERVO: J8.3; also elsewhere on the board
GND: C1.2, C2.2, C3.2, C4.2, C5.2, J3.2, J4.2, J5.2, J6.2, J7.2, J8.1; also elsewhere on the board
V7V5_LEG: C1.1, C2.1, C3.1, C4.1, J3.1, J4.1, J5.1, J6.1, J8.2; also elsewhere on the board
V12_HIP: C5.1, J7.1; also elsewhere on the board


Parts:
J9: FE-URT-1; PinHeader_1x02_P2.54mm_Vertical
JP1: JP_BUS_MASTER; PinHeader_1x03_P2.54mm_Vertical
U6: Teensy4.1; Teensy_4.1
U7: 74HC125; SOIC-14_3.9x8.7mm_P1.27mm

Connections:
+3V3: U6.1, U7.10, U7.13, U7.14 (VCC); also elsewhere on the board
/04 Bus Master (Pattern B)/MASTER_A: J9.2, JP1.1
/04 Bus Master (Pattern B)/MASTER_B: JP1.3, U7.3
/04 Bus Master (Pattern B)/OE_RX: U6.6, U7.4
/04 Bus Master (Pattern B)/OE_TX: U6.5, U7.1
/04 Bus Master (Pattern B)/TEENSY_RX: U6.4, U7.6
/04 Bus Master (Pattern B)/TEENSY_TX: U6.3, U7.2
BATT_LOW: U6.9; also elsewhere on the board
BUS_SIGNAL: JP1.2, U7.5; also elsewhere on the board
GND: J9.1, U6.2, U7.7 (GND), U7.9, U7.12; also elsewhere on the board
I2C_SCL: U6.8; also elsewhere on the board
I2C_SDA: U6.7; also elsewhere on the board


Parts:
J1: XT60_4S_IN; AMASS_XT60-M_1x02_P7.20mm_Vertical
M1: Voltmeter_DC; PinHeader_1x02_P2.54mm_Vertical
Q1: IRLB3034PBF; TO-220-3_Vertical
SW1: Rocker_30A; TerminalBlock_Philmore_TB132_1x02_P5.00mm_Horizontal

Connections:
/01 Battery Input + Reverse Protection/BATT_NEG: J1.2, Q1.2 (S)
/01 Battery Input + Reverse Protection/VBAT: J1.1, SW1.1 (A)
GND: M1.2, Q1.3 (D); also elsewhere on the board
VBAT_PROTECTED: M1.1, Q1.1 (G), SW1.2 (B); also elsewhere on the board

Board: 4 copper layers, 55 parts (0 on the bottom side), 38 nets, no tracks yet.

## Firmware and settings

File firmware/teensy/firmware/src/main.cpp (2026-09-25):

// Nova-SM3 LE — Teensy 4.1 firmware skeleton
// Pattern B bus master per BOM v3.3
//
// Status (2026-05-19): Arduino-only compile-green scaffold. micro-ROS
// integration is gated on NOVA_USE_MICRO_ROS — leave undefined until
// we move firmware builds to the Jetson (Mac micro-ROS build path is
// brittle: needs Python 3.10/3.11 + ROS dev libs). Stubs printed over
// USB-CDC at NOVA_LOOP_HZ for now.

#include <Arduino.h>
#include "feetech_bus.h"
#include "ina226_telemetry.h"
#include "icm42688.h"
#include "hfe_envelope.h"
#include "slew_limiter.h"
#include "safety_state.h"
#include "loop_timing.h"
#include "limp_controller.h"
#include "servo_fleet.h"
#include "telemetry_schedule.h"

// Joint count = 12 (4 legs × 3 joints). Names/frame_id stay empty in
// skeleton — Nova URDF wiring lands once gait controller is on the Jetson.
// Declared outside the micro-ROS ifdef so bus / servo polling code in the
// Arduino-only CI build can size its buffers consistently.
constexpr size_t NOVA_JOINT_COUNT = 12;

// Latched joint-command state — written by the micro-ROS subscriber
// callback (when present) and consumed by broadcast_servo_commands().
// Lives outside the micro-ROS ifdef so the CI build still links against
// the bus driver. In CI / Arduino-only mode this array stays zeroed.
volatile uint32_t joint_cmd_rx_count = 0;
double latched_cmd_position[NOVA_JOINT_COUNT] = {0};

// ---------------- Command-staleness failsafe ----------------
// If /joint_commands stops arriving (USB cable out, Jetson panic, agent
// crash) the broadcast path would otherwise re-send the last target
// forever — robot frozen mid-step with torque held until LVC. Instead:
// after NOVA_CMD_STALE_TIMEOUT_US without a fresh command, overwrite the
// latched targets with the latest MEASURED positions (freeze in place —
// the slew limiter turns that into a gentle decel) and flag /command_stale.
// "Neutral stand pose" is deliberately NOT used: calibration offsets live
// on the Jetson, so raw stand-pose values are meaningless at this layer.
// Recovery is automatic — any fresh command clears the flag and slews
// from the frozen pose to the new target.
#ifndef NOVA_CMD_STALE_TIMEOUT_US
#define NOVA_CMD_STALE_TIMEOUT_US 500000UL   // 500 ms
#endif
uint32_t last_joint_cmd_us = 0;   // stamped in joint_cmd_callback (executor
                                  // runs in tick context — no ISR race)
bool     cmd_stale = false;
uint32_t cmd_stale_events = 0;    // lifetime count, for diagnostics

// Safety state machine — instance + clear-request flag declared up here so
// the bus-write gate (broadcast_servo_commands()) can refuse to fire when a
// latch is active. Definition body lives in safety_state.h.
nova::SafetyFSM safety_fsm;
volatile bool safety_clear_request = false;

// ---------------- Soft-fault controlled limp (#145) ----------------
// This used to be a single unconditional set_fleet_torque(false) the
// instant any latch tripped. See limp_controller.h for exactly which
// faults now get a controlled limp (command a pose, hold torque ~1s, then
// release) instead of that instant release, and why. Declared up here
// (not next to the other host-table state below) because poll_one_servo()'s
// overload path needs to reset it and that function is defined before the
// rest of this file's table-publishing state.
//
// `limp_pose` sub: 12 raw counts, bus-ID order — the SAME host-table
// mechanism as joint_limits/hfe_envelope below (nova_ops safety_envelope/
// limp_pose.py). Until it has arrived at least once, limp_pose_valid stays
// false and main.cpp falls back to the pre-#145 instant release — a
// guessed pose commanded during a live fault is a worse hazard than none.
uint16_t limp_pose_raw[NOVA_JOINT_COUNT];
bool limp_pose_valid = false;
volatile uint32_t limp_pose_rx_count = 0;
nova::LimpController limp_controller;

// Boot self-test result bitmap — set in setup() after GPIO pinMode but
// before the tick timer starts. Bits:
//   0 = ESTOP_PIN read HIGH at boot (button pressed / contact open at
//       startup — operator fault, refuse to arm)
//   1 = BATTERY_LOW_PIN read HIGH at boot (pack already under 13.03V
//       measured-parts trip — refuse to arm)
// Non-zero result means safety_fsm pre-seeded to a latched fault.
uint8_t boot_self_test_flags = 0;

#ifndef NOVA_BUILD_GIT_SHA
#define NOVA_BUILD_GIT_SHA "unknown"
#endif

#ifdef NOVA_USE_MICRO_ROS
#include <micro_ros_platformio.h>
#include <rcl/rcl.h>
#include <rclc/rclc.h>
#include <rclc/executor.h>
#include <std_msgs/msg/int32.h>
#include <std_msgs/msg/bool.h>
#include <std_msgs/msg/float32_multi_array.h>
#include <std_msgs/msg/string.h>
#include <sensor_msgs/msg/joint_state.h>
#include <sensor_msgs/msg/imu.h>
#endif

// ---------------- Pinout ----------------
// Pin numbers reconciled to nova_pcb_v6_logic board routing 2026-06-14.
// UART1 (Serial1) → 74HC125 → Feetech bus
constexpr uint8_t BUS_RX_PIN     = 0;   // Serial1 RX (board: U6 pad TEENSY_RX → pin 0)
constexpr uint8_t BUS_TX_PIN     = 1;   // Serial1 TX (board: U6 pad TEENSY_TX → pin 1)
constexpr uint8_t BUS_OE_TX_PIN  = 2;   // 74HC125 OE̅ for TX gate (ACTIVE-LOW: LOW = enable TX)
constexpr uint8_t BUS_OE_RX_PIN  = 3;   // 74HC125 OE̅ for RX gate (ACTIVE-LOW: LOW = enable RX)
// I2C0 (Wire) — INA226 ×3
constexpr uint8_t I2C_SDA_PIN    = 18;
constexpr uint8_t I2C_SCL_PIN    = 19;
// Safety GPIO
constexpr uint8_t ESTOP_PIN       = 5;   // E-stop NC contact (J21) w/ INPUT_PULLUP. NC closed = LOW idle;
                                         // pressed OR wire-break/unplug = HIGH (fail-safe)
constexpr uint8_t BATTERY_LOW_PIN = 4;   // input from 13.03V comparator (measured-parts; HIGH = below 13.03V)
constexpr uint8_t LED_PIN         = LED_BUILTIN;

// ---------------- Feetech bus (Pattern B half-duplex via 74HC125) ----------------
// Bus class owns the OE pins + Serial1; service_bus_stub still just toggles
// direction until 74HC125 + a real servo are on the bench. Once hardware
// lands, replace the toggle with a round-robin ping/read cycle — the Bus
// instance already has ping(), read_position(), write_goal_position(), and
// sync_write_goal_positions() ready to go.
feetech::Bus servo_bus(BUS_OE_TX_PIN, BUS_OE_RX_PIN, NOVA_BUS_BAUD);

inline void bus_set_tx() { servo_bus.set_tx(); }
inline void bus_set_rx() { servo_bus.set_rx(); }

// ---------------- Stubs (TODO list) ----------------
// service_bus_stub: replace with round-robin ping/read when servos on bench
// read_ina226_stub: integrate Rob Tillaart's INA226 library, 3 rails
// publish_topics:   wire micro-ROS publishers when NOVA_USE_MICRO_ROS defined

void service_bus_stub() {
  // Toggle direction pins so we can scope them during bring-up
  bus_set_tx();
  delayMicroseconds(1);
  bus_set_rx();
}

// ---------------- INA226 power-rail telemetry ----------------
// 3 mandatory rails per BOM v3.4. Optional 4th (L2 LiDAR) gated by
// NOVA_INA226_L2. Round-robin one rail per tick so each chip refreshes at
// LOOP_HZ / N_RAILS (≈ 66 Hz for 3 rails @ 200 Hz tick) — well above the
// 10 Hz /diagnostics publish rate.
nova::Rail rail_leg   (nova::INA226_ADDR_LEG,    "leg_7v5");
nova::Rail rail_hip   (nova::INA226_ADDR_HIP,    "hip_12v");
nova::Rail rail_jetson(nova::INA226_ADDR_JETSON, "jetson_12v");
#ifdef NOVA_INA226_L2
nova::Rail rail_l2    (nova::INA226_ADDR_L2,     "l2_12v");
constexpr uint8_t INA226_RAIL_COUNT = 4;
nova::Rail* rails[INA226_RAIL_COUNT] = {&rail_leg, &rail_hip, &rail_jetson, &rail_l2};
#else
constexpr uint8_t INA226_RAIL_COUNT = 3;
nova::Rail* rails[INA226_RAIL_COUNT] = {&rail_leg, &rail_hip, &rail_jetson};
#endif
uint8_t ina226_rr_idx = 0;

// ---------------- ICM-42688-P IMU (#14, #289 step 4) ----------------
// The Wire transport lives HERE, not in icm42688.h, so the header stays free
// of Arduino and the decode + filter stay native-testable (test_icm42688).
//
// NOT ON THE BOARD YET. The breakout is unordered (improvement-backlog item
// 14). icm_begin() gates on WHO_AM_I, so with no chip present imu_ok stays
// false, nothing is polled and nothing is published -- the same
// absent-sensor discipline Rail::begin() already uses. It costs one failed
// I2C transaction at boot.
nova::TiltFilter imu_filter;
nova::ImuSample imu_sample;
bool imu_ok = false;
uint32_t imu_last_us = 0;
volatile uint32_t imu_sample_count = 0;

static bool icm_write(uint8_t reg, uint8_t val) {
  Wire.beginTransmission(nova::ICM_ADDR);
  Wire.write(reg);
  Wire.write(val);
  return Wire.endTransmission() == 0;
}

static bool icm_read(uint8_t reg, uint8_t* buf, uint8_t n) {
  Wire.beginTransmission(nova::ICM_ADDR);
  Wire.write(reg);
  if (Wire.endTransmission(false) != 0) return false;
  if (Wire.requestFrom((int)nova::ICM_ADDR, (int)n) != n) return false;
  for (uint8_t i = 0; i < n; i++) buf[i] = Wire.read();
  return true;
}

// Returns false unless WHO_AM_I reads back 0x47. That check is the only thing
// standing between a mis-remembered register map and plausible garbage in the
// first six dims of every observation frame -- fail closed, loudly.
bool icm_begin() {
  uint8_t who = 0;
  if (!icm_read(nova::ICM_REG_WHO_AM_I, &who, 1)) return false;
  if (who != nova::ICM_WHO_AM_I_VALUE) return false;
  if (!icm_write(nova::ICM_REG_DEVICE_CONFIG, 0x01)) return false;  // soft reset
  delay(2);
  if (!icm_write(nova::ICM_REG_GYRO_CONFIG0, nova::ICM_GYRO_CFG_2000DPS_1KHZ)) return false;
  if (!icm_write(nova::ICM_REG_ACCEL_CONFIG0, nova::ICM_ACCEL_CFG_16G_1KHZ)) return false;
  if (!icm_write(nova::ICM_REG_PWR_MGMT0, nova::ICM_PWR_LN_BOTH)) return false;
  delay(1);   // datasheet asks for a settling gap after leaving OFF mode
  imu_filter.reset();
  return true;
}

// One 12-byte burst: accel XYZ then gyro XYZ, contiguous from ACCEL_DATA_X1.
void poll_imu(uint32_t now_us) {
  if (!imu_ok) return;
  uint8_t b[12];
  if (!icm_read(nova::ICM_REG_ACCEL_DATA_X1, b, 12)) return;
  imu_sample = nova::icm_decode(b);
  float dt = (imu_last_us == 0) ? 0.001f : (float)(now_us - imu_last_us) * 1e-6f;
  imu_last_us = now_us;
  if (dt > 0.0f && dt < 0.1f) imu_filter.update(imu_sample.gyro, imu_sample.accel, dt);
  imu_sample_count++;
}

void read_ina226_stub() {
  // Round-robin sample. Single chip per tick keeps the I²C bus + main loop
  // budget tight; full set refreshes every INA226_RAIL_COUNT ticks.
  rails[ina226_rr_idx]->poll();
  ina226_rr_idx = nova::rr_next(ina226_rr_idx, INA226_RAIL_COUNT);
}

// ---------------- Servo round-robin telemetry ----------------
// One servo read per tick (5 ms budget at 200 Hz). Bus read costs ~80 µs TX
// + ~1.5 ms response (or full timeout if servo absent). At 12 joints,
// full-fleet refresh = 60 ms = ~17 Hz per joint — adequate for /joint_states
// at the planned 100 Hz aggregate. Servo IDs are 1..NOVA_JOINT_COUNT by
// convention; ID 0 is unused (reserved), ID 0xFE is broadcast.
constexpr uint8_t SERVO_ID_BASE = 1;
uint8_t servo_rr_idx = 0;     // 0..NOVA_JOINT_COUNT-1 → servo ID = SERVO_ID_BASE + idx
// Per-servo telemetry. All raw — gait layer on the Jetson converts to
// radians + Newton-metres using URDF + servo calibration.
//   position:    0..4095 (12-bit encoder)
//   velocity:    int16 sign-magnitude (STS3215 convention)
//   load:        int16 sign-magnitude (0..1000 raw, % of stall torque)
//   voltage:     u8 in 0.1 V units (e.g. 74 = 7.4 V)
//   temperature: u8 in °C (raw, 0..100 typical operating range)
volatile uint16_t servo_position_raw[NOVA_JOINT_COUNT] = {0};
volatile int16_t  servo_velocity_raw[NOVA_JOINT_COUNT] = {0};
volatile int16_t  servo_load_raw    [NOVA_JOINT_COUNT] = {0};
volatile uint8_t  servo_voltage_raw [NOVA_JOINT_COUNT] = {0};
volatile uint8_t  servo_temp_c      [NOVA_JOINT_COUNT] = {0};

// Last-read success bitmask — bit i set ⇒ servo (SERVO_ID_BASE + i) has
// answered at least once since boot. Exposed as /servo_present_mask for
// host-side fleet inventory.
volatile uint16_t servo_present_mask = 0;

// Categorised bus-error counters (monotonic). All start zero; a non-zero
// value on a host dashboard means something went wrong in that category
// since boot. /servo_read_err_count = sum of these three for backward compat.
volatile uint32_t servo_err_timeout   = 0;
volatile uint32_t servo_err_bad_frame = 0;
volatile uint32_t servo_err_servo     = 0;
volatile uint32_t servo_read_err_count = 0;

// ---------------- Stall / overload guard ----------------
// A jammed/overloaded joint drives full stall current at its unreachable goal
// indefinitely — fries the servo + can brown the hip rail (4× hip stall ≈ 20A
// > buck). Detect sustained high load OR overtemp per joint and LIMP the whole
// fleet (torque off) — same end state as the hardware E-stop. Operator clears
// via /safety_clear once the jam is fixed. Thresholds are build-flag tunable.
#ifndef NOVA_STALL_LOAD_RAW
#define NOVA_STALL_LOAD_RAW 900     // of 1000 = 90% of stall torque
#endif
// Fleet dynamics written on EVERY arm (RAM regs reset on servo power-cycle):
// torque limit 600 permille — gait stance needs ~45% of the 19kg servos, so
// 60% keeps 1.3x headroom while a trip/jam saturates at 60% instead of full
// stall through the gears (leg_v6 movement review, 2026-07-03). Bench
// 2026-09-25 (#466): this register is a PWM DUTY cap (peak duty clamps at
// exactly 600, 3 Hz top speed 2500 -> 2100 steps/s). Raising it is #428.
#ifndef NOVA_TORQUE_LIMIT_RAW
#define NOVA_TORQUE_LIMIT_RAW 600
#endif
// Goal acc 0 = "use the servo's maximum", which is reg 85 Maximum_Acceleration
// (set to 254 at assembly: set-servo-ids.py --set-max-accel). Any NONZERO value
// is the working accel limit: bench 2026-09-25 with reg 85 = 254, acc 50 gave a
// 2 Hz sine ratio of 0.27 (the old ~8.5 rad/s^2 ceiling) while acc 0 or 100 gave
// 0.99. So 50 here silently undid reg 85 on every arm. The torque-on snap it was
// meant to soften is handled by arm() writing goal = present first.
#ifndef NOVA_GOAL_ACC
#define NOVA_GOAL_ACC 0
#endif
#ifndef NOVA_OVERTEMP_C
#define NOVA_OVERTEMP_C 70          // °C — act before the servo's own ~80°C cutoff
#endif
#ifndef NOVA_STALL_PERSIST
#define NOVA_STALL_PERSIST 5        // consecutive bad reads (~300 ms @ ~60 ms/joint poll)
#endif
uint8_t  servo_stall_count[NOVA_JOINT_COUNT] = {0};
volatile uint16_t servo_stall_mask = 0;     // bit i set = joint i has tripped

// Write TORQUE_ENABLE to every PRESENT servo (torque-off: broadcast first, then
// per-servo write + read-back, #437). Blocking (~0.4 ms/servo, more on retry) — only
// called on the first safety tick, on stall-fault entry, and on fault clear;
// never the hot path. The logic lives in servo_fleet.h (native-tested,
// test_servo_fleet); arming is refused until the first safety tick (#436).
nova::ServoFleet<feetech::Bus> servo_fleet(servo_bus, SERVO_ID_BASE, NOVA_JOINT_COUNT,
                                           NOVA_TORQUE_LIMIT_RAW, NOVA_GOAL_ACC);
void set_fleet_torque(bool on) {
  if (on) servo_fleet.arm(servo_present_mask);
  else    servo_fleet.disarm(servo_present_mask);
}
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
void loop() {
  // Software-watchdog kick — bump the progress counter every iteration.
  // The ISR observes this from a hardware timer, independent of any main-
  // loop pathology (blocking publish, deadlocked rcl call, etc.).
  main_loop_iter++;

  // Atomic snapshot of ISR flag + timestamp
  noInterrupts();
  bool     pending = tick_pending;
  uint32_t fire_us = tick_isr_us;
  tick_pending = false;
  interrupts();

  if (pending) {
    // Response latency = elapsed time from ISR firing to handler entry.
    // Bare metric is "how late are we to service the tick" — sub-µs is
    // possible on M7 when no contending ISR/spin work blocks the loop().
    uint32_t handler_start_us = micros();
    uint32_t latency_us = handler_start_us - fire_us;

    latency_hist.record(latency_us);

    // Servo bus — one read per tick (round-robin) + decimated SYNC_WRITE
    // broadcast of the latest joint_commands. Both no-ops at the wire level
    // until a real STS3215 is on the bench: poll_one_servo() times out and
    // increments servo_read_err_count; broadcast_servo_commands() sends the
    // sync-write frame but no servo will ACK (broadcast doesn't expect
    // ACK anyway). The OE pin toggle in service_bus_stub() is no longer
    // needed — Bus::transmit_blocking() handles direction switching.
    // Command-staleness failsafe — evaluate BEFORE the broadcast so a
    // freeze takes effect on this tick's SYNC_WRITE, not the next.
    if (joint_cmd_rx_count > 0) {
      bool stale_now =
          (uint32_t)(handler_start_us - last_joint_cmd_us) > NOVA_CMD_STALE_TIMEOUT_US;
      if (stale_now && !cmd_stale) {
        cmd_stale = true;
        cmd_stale_events++;
        // Freeze: retarget every joint that has ever answered a poll to its
        // latest measured position. Joints that never answered keep their
        // last commanded target (no better information exists for them).
        for (size_t i = 0; i < NOVA_JOINT_COUNT; i++) {
          if (servo_present_mask & (uint16_t)(1u << i)) {
            latched_cmd_position[i] = (double)servo_position_raw[i];
          }
        }
      } else if (!stale_now && cmd_stale) {
        cmd_stale = false;   // fresh command arrived — normal slew resumes
      }
    }

    // Feedback poll: N servos per tick (backlog #21 — was 1/tick = 17 Hz
    // per joint, the gait/contact-detection ceiling). 3/tick at 200 Hz =
    // 50 Hz per joint; bus cost ~3 x 370 us = 1.1 ms of the 5 ms tick,
    // plus the 100 Hz sync-write (~0.5 ms every 2nd tick). Watch the
    // exec-time p99 histogram after flashing; 4/tick (66 Hz) fits if
    // needed. SYNC_READ (one frame, all 12) would reach ~200 Hz — probe
    // whether the servos' firmware supports instruction 0x82 at bring-up.
    for (uint8_t pk = 0; pk < NOVA_POLLS_PER_TICK; pk++) poll_one_servo();
    broadcast_servo_commands();

    // Telemetry sample
    read_ina226_stub();
    poll_imu(handler_start_us);

    // Safety GPIO sense + state-machine update
    bool estop_now = (digitalRead(ESTOP_PIN) == HIGH);   // HIGH = pressed/open (NC fail-safe)
    bool batt_low_now = (digitalRead(BATTERY_LOW_PIN) == HIGH);
    nova::SafetyState prev_safety = safety_fsm.state();
    safety_fsm.update(estop_now, batt_low_now);
    if (safety_clear_request) {
      safety_fsm.clear();
      safety_clear_request = false;
    }
    nova::SafetyState curr_safety = safety_fsm.state();
    // #145: on any NEW latch (E-stop / battery-low; the stall path already
    // cut torque itself before tripping, above), decide instant release vs
    // controlled limp per fault type — see limp_controller.h. Holding the
    // last pose with torque enabled indefinitely fights the operator and
    // cooks servos against whatever caused the stop; the difference #145
    // adds is a SHORT, bounded, commanded settle for the faults where that
    // is safe. (system-audit item "E-stop limp", closed 2026-07-06)
    if (curr_safety != nova::SAFETY_NORMAL && prev_safety == nova::SAFETY_NORMAL) {
      if (nova::fault_gets_controlled_limp(curr_safety) && limp_pose_valid) {
        limp_controller.start(limp_pose_raw, handler_start_us);
        // Torque stays ON. broadcast_servo_commands() (already called this
        // tick, above) starts ramping toward limp_controller.target() on the
        // NEXT tick; set_fleet_torque(false) is deferred to the hold-elapsed
        // check below.
      } else {
        // E-stop, overload, or a battery-low fault with no pose on record
        // yet (pre-homing / haa sign unconfirmed): fail safe to the original
        // instant release rather than guess a pose or delay an E-stop.
        set_fleet_torque(false);
      }
    }
    // E-stop always wins, even over an in-progress controlled limp — a
    // human pressing E-stop mid-limp must not wait out the remaining hold
    // window. (The FSM itself won't relatch state on top of an existing
    // fault, so this reads the RAW pin rather than curr_safety.)
    if (limp_controller.active() && estop_now) {
      set_fleet_torque(false);
      limp_controller.reset();
    } else if (limp_controller.tick(handler_start_us)) {
      // Hold window elapsed — release exactly like the instant path always did.
      set_fleet_torque(false);
      limp_controller.reset();
    }
    // On any transition back to NORMAL (clear succeeded), reset the slew
    // history so the next broadcast accepts the current target verbatim
    // rather than ramping from the stale pre-fault goal.
    if (curr_safety == nova::SAFETY_NORMAL && prev_safety != nova::SAFETY_NORMAL) {
      slew_init_all();
      // Fault cleared → re-arm torque + reset the stall guard so it re-protects.
      set_fleet_torque(true);
      servo_stall_mask = 0;
      for (size_t i = 0; i < NOVA_JOINT_COUNT; i++) servo_stall_count[i] = 0;
      limp_controller.reset();   // defensive — should already be idle here
    }
    // #436: boot arm, on the FIRST safety tick — the FSM has just evaluated
    // the live E-stop / battery-low pins, the tick timer and watchdog are
    // running. Arm servo torque on every present servo (decision 2026-06-27:
    // FW ALWAYS writes TORQUE_ENABLE rather than trusting each servo's EEPROM
    // default — a torque-off EEPROM would silently ignore every goal). Skipped
    // if booting into a latched fault (boot self-test); the clear path above
    // re-arms. No-op on every later tick.
    servo_fleet.safety_tick(safety_fsm.motion_enabled(), servo_present_mask);
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

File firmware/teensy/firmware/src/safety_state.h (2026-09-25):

// Safety state machine — E-stop latch + battery-low debounce + master motion
// enable. Wired into the 200 Hz tick. Pure logic, no Arduino calls except
// micros() — pin reads happen in main.cpp and feed in via update().
//
// Latching rule (Phase 1 spec, BOM §"safety chain"): once E-stop is pressed
// or battery_low debounce trips, the master torque-enable flag drops and
// stays dropped until an explicit clear signal arrives (e.g. /safety_clear
// topic on Jetson side, or power cycle). This prevents a glitchy GPIO from
// re-arming the servos mid-fault.

#pragma once

#include <Arduino.h>

namespace nova {

enum SafetyState : uint8_t {
  SAFETY_NORMAL              = 0,
  SAFETY_ESTOP_LATCHED       = 1,
  SAFETY_BATTERY_LOW_LATCHED = 2,
  SAFETY_FAULT_OTHER         = 3,   // reserved for future faults (bus, INA, etc.)
};

class SafetyFSM {
 public:
  // Battery-low debounce: N consecutive ticks of HIGH on the comparator
  // before we latch. At 200 Hz tick, 10 samples = 50 ms — long enough to
  // ride out a single capacitive glitch, short enough to react before the
  // 12.56 V MOSFET hard-cutoff fires (measured-parts value; was estimated
  // 12.4 V — see hardware/wiring/README.md's safety-chain trip-point table).
  static constexpr uint8_t BATT_LOW_DEBOUNCE_TICKS = 10;

  void update(bool estop_pressed_now, bool batt_low_now) {
    // E-stop trips immediately, no debounce (mechanical switch already
    // contact-bounce-clean from the BOM v3.4 wiring).
    if (estop_pressed_now && state_ == SAFETY_NORMAL) {
      state_ = SAFETY_ESTOP_LATCHED;
      transition_us_ = micros();
    }

    // Battery-low: debounced
    if (batt_low_now) {
      if (batt_low_count_ < 0xFF) batt_low_count_++;
    } else {
      batt_low_count_ = 0;
    }
    if (batt_low_count_ >= BATT_LOW_DEBOUNCE_TICKS && state_ == SAFETY_NORMAL) {
      state_ = SAFETY_BATTERY_LOW_LATCHED;
      transition_us_ = micros();
    }

    // Mirror latest raw signals for telemetry — the published /estop and
    // /battery_low topics surface the raw GPIO, not the latched state, so
    // a host operator can see when the source signal is back to clear.
    estop_raw_ = estop_pressed_now;
    batt_low_raw_ = batt_low_now;
  }

  // Trip a fault that has no raw GPIO of its own (servo stall / overload /
  // overtemp). Latches like E-stop; cleared only via clear() (operator
  // /safety_clear) once the jam is resolved. motion_enabled() drops and
  // main.cpp torque-disables the fleet on entry.
  void trip_overload() {
    if (state_ == SAFETY_NORMAL) {
      state_ = SAFETY_FAULT_OTHER;
      transition_us_ = micros();
    }
  }

  // Clear latched faults — only valid when underlying signals are no
  // longer asserted. Returns true if a clear actually happened.
  bool clear() {
    if (state_ == SAFETY_NORMAL) return false;
    if (estop_raw_)    return false;       // refuse while E-stop still held
    if (batt_low_raw_) return false;       // refuse while battery still low
    state_ = SAFETY_NORMAL;
    batt_low_count_ = 0;
    transition_us_ = micros();
    return true;
  }

  SafetyState state() const          { return state_; }
  bool motion_enabled() const        { return state_ == SAFETY_NORMAL; }
  uint32_t time_since_transition_us() const { return micros() - transition_us_; }

 private:
  SafetyState state_ = SAFETY_NORMAL;
  uint8_t  batt_low_count_ = 0;
  bool     estop_raw_ = false;
  bool     batt_low_raw_ = false;
  uint32_t transition_us_ = 0;
};

}  // namespace nova

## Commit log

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2026-05-19 firmware: Teensy skeleton compile-green on Mac (Arduino-only path)
    micro-ROS lib_deps temporarily commented out — Mac build path is
    brittle (Python 3.14 + missing ROS dev libs cause colcon to choke
    during micro_ros_platformio's dev-deps build phase). Gate the
    micro-ROS calls behind NOVA_USE_MICRO_ROS define so the rest of the
    skeleton compiles clean now. Reinstate the lib_deps + define on the
    Jetson once we move firmware builds there for live agent testing.
    ## What works now (compile-green)
    - platformio.ini: env=teensy41, framework=arduino, build_flags set
    for NOVA_BUS_BAUD=1000000, NOVA_LOOP_HZ=200
    - src/main.cpp: GPIO scaffolding for 74HC125 TX/RX OE pins, Serial2
    init for the Feet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
    [main.cpp]
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2026-05-19 firmware: 200 Hz tick jitter harness, /loop_max_us + /loop_p99_us pubs
    Replace elapsedMillis tick gate with us-resolution prev_tick_us stride
    (no drift from execution time, signed-compare handles micros() wrap).
    Each tick lands in a 100-bucket histogram (0..10 ms + overflow); per-
    window max + p99 published at 1 Hz on two new Int32 topics.
    Baseline measured on Jetson agent (stubs only, no executor spin, no
    bus traffic): p99 ≈ 5050 us (50 us late at 99th percentile, ~1%
    jitter), max single tick ≈ 5600 us. Real numbers will grow once
    Feetech bus reads + INA226 I2C + executor spin land — this is the
    intrinsic-loop lower bound for the p99 < 2 ms acceptance gate.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
    [main.cpp]
2026-05-20 firmware: topic contract — JointState pub/sub, estop, battery_low, rx_count
    Adds:
    - /joint_states (sensor_msgs/JointState, 12 joints zeros + millis stamp, 200 Hz)
    - /estop, /battery_low (std_msgs/Bool, edge-change publish only)
    - /joint_commands (sensor_msgs/JointState sub, no-op callback latches
    position into latched_cmd_position[] for the gait/servo layer)
    - /joint_cmd_rx_count (std_msgs/Int32, exposes callback fire count at
    1 Hz — confirms host->target round-trip without scope)
    - rclc_executor wired w/ ON_NEW_DATA spin_some() each tick
    Verified on Jetson agent: pub /joint_commands ×5 → rx_count 0→5 exactly,
    no loop jitter regression (p99 unchanged at 5050 us).
    JointState na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
    [main.cpp]
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2026-05-20 firmware: IntervalTimer ISR-driven tick, p99 = 1 µs (50× improvement)
    Replace polled micros() period gate with IntervalTimer ISR at 200 Hz.
    ISR sets a pending flag + captures the fire timestamp; the main loop
    services the tick on the next iteration and measures ISR→handler
    response latency.
    Metric semantics changed: /loop_max_us and /loop_p99_us now report
    response-latency µs (target 0, jitter = pure scheduling cost), not
    actual_period - nominal. Histogram retuned to 2 µs × 64 buckets =
    0..128 µs, overflow as final bucket.
    Measured on Jetson agent (stubs only, micro-ROS publishes + executor
    spin in handler):
    - p99 = 1 µs (was 50 µs late at 99th pct with polled tick → 50×)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
    [main.cpp]
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2026-05-20 firmware: tick exec-time + tick_missed telemetry, generalize p99
    Three new Int32 publishers at 1 Hz:
    /loop_exec_max_us — max handler-body execution time (window)
    /loop_exec_p99_us — p99 of handler-body execution (10 µs buckets)
    /tick_missed_count — monotonic count of ISR fires that found the
    previous tick still pending (i.e. main loop
    didn't service the prior tick before the next
    deadline). Always 0 in healthy state.
    compute_p99_us() now parameterised on (histogram, n_buckets,
    bucket_us, total_count) so the same routine handles both the 2 µs
    response-latency and 10 µs exec-time buckets. tick_missed
    deliber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
    [main.cpp]
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2026-05-20 firmware: safety FSM (E-stop + battery-low latch), SCServo extended ops
    safety_state.h — SafetyFSM class
    Two-trigger latching state machine:
    - E-stop GPIO press → SAFETY_ESTOP_LATCHED (immediate, no debounce
    since the panel-mount NC switch is mechanically debounced).
    - Battery-low comparator HIGH for 10 consecutive ticks (50 ms at
    200 Hz) → SAFETY_BATTERY_LOW_LATCHED. Single-glitch immune,
    reacts well before the 12.4 V MOSFET hard-cutoff fires.
    motion_enabled() == (state == SAFETY_NORMAL). The bus / gait layer
    will gate SYNC_WRITE on this once a real servo is on the bench.
    clear() refuses while underlying signals still asserted — spurious
    /safety_c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
    [feetech_bus.h, main.cpp, safety_state.h]
2026-05-20 firmware: /power_rails Float32MultiArray pub @ 10 Hz from INA226 samples
    Publishes a 9-float snapshot of the 3 mandatory rails on /power_rails:
    data[0..2] = leg_7v5 (bus_voltage_v, current_a, power_w)
    data[3..5] = hip_12v
    data[6..8] = jetson_12v
    Fixed-layout, no MultiArrayDimension entries — consumers read by index
    per the order above. Optional 4th L2 rail (when NOVA_INA226_L2 is
    defined) is sampled by the INA226 round-robin but intentionally not
    included in this msg; downstream consumers expect the 9-float layout.
    power_rails_data[] buffer lives outside the micro-ROS ifdef so the
    Arduino-only CI build also exercises the rail-sample copy path; only
    the rcl_publish itself is gat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
    [main.cpp]
2026-05-20 firmware: close the bus loop — servo poll/cmd wired into tick handler
    Replaces the OE-toggle service_bus_stub() with a real per-tick servo
    poll + decimated SYNC_WRITE broadcast. No behaviour change at the
    wire level until a real STS3215 is on the bench (every read times
    out, broadcast is fire-and-forget); but the topology is now
    end-to-end, ready to come alive when the 74HC125 + a servo land.
    Servo poll path
    poll_one_servo() reads REG_PRESENT_POSITION_L from one servo per
    tick, round-robin across IDs 1..12. Successful reads update
    servo_position_raw[i] + set bit i in servo_present_mask. Failures
    increment servo_read_err_count. Full-fleet refresh = 12 ticks at
    200 Hz = 60 ms ≈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
    [main.cpp]
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2026-05-20 firmware: full STS3215 telemetry (pos+vel+load) + categorised bus errors
    feetech_bus.h — new read_block() helper
    Pulls `len` consecutive bytes starting at `reg` into a caller buffer in
    a single READ_DATA frame. Wraps build_read + transmit_blocking + parse
    + payload copy with the standard Result return. Used by the per-tick
    telemetry sweep below; reusable for any future multi-byte register
    query (voltage + temperature at 0x3E/0x3F, EEPROM dumps, etc.).
    main.cpp — per-servo telemetry triple
    poll_one_servo() now reads 6 consecutive bytes from REG_PRESENT_
    POSITION_L = 0x38: position (u16 little-endian, 0..4095) + velocity
    (s16 sign-magnitude, STS3215 convention) + load (s16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
    [feetech_bus.h, main.cpp]
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2026-05-21 firmware: per-joint voltage + temperature telemetry @ 5 Hz
    Extends the per-tick servo sweep from 6 to 8 bytes:
    REG_PRESENT_POSITION_L (0x38) .. REG_PRESENT_TEMPERATURE (0x3F)
    New fields cached per joint:
    servo_voltage_raw[i] — u8 in 0.1 V units (e.g. 74 = 7.4 V nominal)
    servo_temp_c[i] — u8 in °C (0..100 typical operating)
    Two new Float32MultiArray publishers at 5 Hz:
    /servo_voltage — 12 floats in volts (raw * 0.1)
    /servo_temperature — 12 floats in °C
    The scaling math (raw * 0.1 for voltage) happens firmware-side so
    host-side consumers see calibrated units, not raw bytes. Same fixed-
    layout pattern as /power_rails — read by joint index, no
    MultiArrayLayout d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
    [main.cpp]
2026-05-21 firmware: per-joint slew limiter on SYNC_WRITE goal broadcast
    Caps the per-broadcast change in goal position to NOVA_SLEW_MAX_DELTA
    raw encoder units (default 50, override at compile time). At the
    40 Hz broadcast rate (1 every 5 ticks @ 200 Hz) this works out to
    ~176°/s — slow enough to absorb a step-jump command without slamming
    joints, fast enough that intentional gait motion isn't visibly
    attenuated.
    Protects against:
    - Host crash + restart at a far-away target pose (one of the more
    common ways to break a servo gearbox during early bring-up).
    - Lost /joint_commands packets resuming with stale data.
    - Mistuned gait controller emitting impulse commands.
    last_cmd_goal[i] = SLE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
    [main.cpp]
2026-05-21 firmware: software watchdog — ISR-checked main-loop progress, AIRCR reset on hang
    A 200-tick (1 s @ 200 Hz) software watchdog runs inside the existing
    IntervalTimer ISR. Main loop increments main_loop_iter at the top of
    each loop() iteration; the ISR observes the counter and resets
    no_progress_ticks on advance. If the counter stalls for
    NOVA_WATCHDOG_TICKS consecutive ISR fires, the ISR writes 0x05FA0004
    to SCB_AIRCR (ARMv7-M system reset request) — CPU reboots, firmware
    restarts cold.
    Catches:
    - blocking rcl_publish() / rcl call w/ no agent on the other end
    - infinite loop in a callback
    - deadlock in any future shared-state add (e.g. mutex on a non-
    realtime path)
    - random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
    [main.cpp]
2026-05-21 firmware: boot-time servo ping sweep — first /servo_present_mask is real
    setup() now pings each servo ID 1..12 once, sequentially, with a
    1 ms per-ID timeout. Successful responses set the matching bit in
    servo_present_mask before tick_timer.begin().
    Why: the round-robin telemetry reader takes 12 ticks × 5 ms = ~60 ms
    to discover the full fleet, and the 1 Hz /servo_present_mask publish
    won't carry a useful value for ~720 ms after boot. With this sweep,
    the first publish reports actual inventory immediately — the
    operator sees which joints are missing on first heartbeat instead
    of guessing while the rotating reader catches up.
    Worst-case setup() cost: 12 × 1 ms = 12 ms when the entire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
    [main.cpp]
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2026-05-24 cad: leg V3.1 — body-driven dual-shaft yoke architecture
    Replaces V3 single-shaft cantilever design after user clarification on
    2026-05-24 of the correct leg kinematics + servo mounting style.
    Architecture:
    - Servo 1 (hip abduction, 30 kg STS3215): shoulder yoke -> coax body
    - Servo 2 (thigh flexion, 19 kg): coax yoke -> femur body
    - Servo 3 (knee, 19 kg): femur yoke -> tibia body
    Every upstream link is a U-yoke (horn arm + 688ZZ bearing arm) straddling
    the servo along its shaft axis. Downstream link is a body shell pocket
    that surrounds the STS3215 body, rotating with it. Dual-shaft support on
    every joint — no cantilever loading on splines.
    Body-shell pieces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
    [coax_v31_cover.stl, coax_v31_shell.stl, femur_v31_cover.stl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]
2026-05-24 cad: V3.1 connectivity fix + connectivity gate in skill
    Fixes the disconnected-component bug user spotted on coax + femur:
    Root cause: CadQuery boolean unions are fragile at sub-1 mm overlaps.
    The body-beam-yoke unions in coax + femur had ~1 mm overlap which
    left disconnected solids that were still individually watertight
    (both pieces closed surfaces) so the --strict watertight check did
    not catch the defect.
    Fixes:
    - coax.py: gap-carve Z range constrained to (-1, YOKE_BOT-0.5) so it
    does not extend into the body shell region above. Was carving
    through the floor of the body shell, splitting it from the yoke.
    - femur.py: beam overlap into body + yoke bumped from 1 mm to 5 mm
    each side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
    [coax_v31_shell.stl, femur_v31_shell.stl, leg_v31_assembly.stl]
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2026-05-24 cad: revert TTL pass-through to 16x9 rect slot (fits 2 cables side-by-side)
    User feedback: prefers the rectangular slot over the round hole. 16x9
    geometry fits 2 TTL cables side-by-side at the cable section (each
    cable ~3 mm wide x ~3 mm tall) and 1 JST 3-pin XH connector with slack
    during install (connector body 7.5 x 5.9 mm + room).
    leg_common.py:
    - WIRE_SLOT_W = 16.0, WIRE_SLOT_H = 9.0 (canonical now)
    - WIRE_HOLE_DIA kept as alias = max(W,H) for any external consumers
    All 4 shells switched back to .rect().extrude() for the cable cut:
    - coax -X face
    - femur -X + +X body faces, mid-link beam channel, +Y/-Y yoke arms
    - tibia -X + +X body faces
    - shoulder chassis slab pass-through
    Connecti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
    [coax_v31_shell.stl, femur_v31_shell.stl, leg_v31_assembly.stl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]
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2026-05-31 cad: archive rejected leg versions V2/V3/V4, reframe docs to three-track
    Move superseded leg designs (V2 hobby-servo original, V3.1 CadQuery,
    V4 OnShape) into hardware/cad/archive/ and make V5 OpenSCAD original-
    shell-carve canonical. Update all CAD docs, BOM, README, project skill,
    and Notion to the three-track workflow (V5 OpenSCAD = leg links,
    CadQuery = utility parts, OnShape = chassis/multi-body).
    Also carries prior-session STEP-verified dimension corrections to
    dimensions.md + patterns.md (STS3215 body Z 34.3 mm, horn screws M2.5
    not M3, impossible 49 mm mount pitch flagged).
    [Femur.step, Femur.stl, HipFrame.step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]
2026-06-03 pcb(v6): commit KiCad 9 schematic — §1-§8 hierarchical, ERC-clean
    54 components footprinted (KiCad-stock libs), pin-name wiring audit
    passed, ERC 0 errors / 1 intentional warning (V7V5_ARM reserved Phase-4
    arm rail, DNP). Off-board load connectors J12 (V12_JET→Jetson) + J13
    (V12_L2→L2 LiDAR) added so both 12V rails terminate at a load. READMEs
    marked schematic-captured. .gitignore: ignore KiCad junk (*.kicad_prl,
    *-backups/, fp-info-cache, *.drc/erc.json).
    [01_battery.kicad_sch, 02_power_rails.kicad_sch, 03_servo_bus.kicad_sch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]
2026-06-06 pcb(v6-power): add split mezzanine power board — floorplan + 4-layer pours
    New nova_pcb_v6_power KiCad 9 project, split from monolithic nova_pcb_v6:
    - 2-sided bucks-free floorplan, DRC-clean (F.Cu low-profile THT; B.Cu tall
    caps + SMD). U1-U5 = Buck_Offboard_Terminal_2xXT30 wire landings (bucks
    off-board in finned holder; netlist unchanged, footprint-property swap).
    - In1.Cu GND + In2.Cu VBAT_PROTECTED copper pours (ratsnest 120->67,
    zero real DRC violations post-fill). Zones unfilled in-file; fill in GUI.
    - Reproducible scripts/floorplan_plan.py (validate) + floorplan_apply.py
    (apply positions). Custom footprints in nova_v6.pretty.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
    [01_battery.kicad_sch, 02_power_rails.kicad_sch, 03_servo_bus.kicad_sch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]
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2026-06-06 pcb(v6-power): route power rails + add HighCurrent/Power netclasses
    Headless-route all power-appropriate rails: RAW buck->INA hops, V12_JET and
    V12_L2 output rails, V7V5_LEG F.Cu pour + J6 tap, V12_HIP INA->C5, and
    V12_L2_RAW buck->inductor. DRC clean (0 errors); 50 ratsnest links remain,
    all GUI-bound (bottom-right logic cluster + 5 power/edge taps boxed behind
    existing B.Cu walls / top THT congestion).
    Add HighCurrent (3.0mm track) and Power (1.5mm) netclasses to .kicad_pro and
    assign the leg/hip rails to HighCurrent. Per IPC-2221 at 2oz outer copper,
    1.5mm carries ~7A @20C rise; hip rail (~9A) and leg trunk exceed that, so
    they need >=3.0mm on any GUI reroute/re-pour. Netclasses govern n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
    [nova_pcb_v6_power.kicad_pcb]
2026-06-12 pcb(v6-power-v2): fork to v2 — full reroute, safety chain, off-board INA226, DRC clean
    - Fork nova_pcb_v6_power -> _v2 (v1 frozen); placement redone power-flow-first
    - Safety chain board sync: Q3 e-stop inverter, Q4 EN_JET cutoff, R16, C8/C9
    - INA226 modules converted off-board: footprints stripped to 4-pin I2C headers,
    RAW nets eliminated (bench wiring card in ROUTING_HANDOFF.md Step 8)
    - All power routed 1.5/3.0mm per netclass, LEG pour L-shape, hip doubled F+B
    - All signal nets routed headless via pre-commit collision checker:
    B.Cu lanes y137.5-139.9 + F.Cu verticals + via pairs; V5_AUX spine gap
    bridged x114.5; board min via relaxed to 0.45/0.25 (PCBWay standard)
    - DRC: 0 errors,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
    [01_battery.kicad_sch, 02_power_rails.kicad_sch, 03_servo_bus.kicad_sch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]
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2026-06-12 pcb(v6-power-v2): bump signal vias 0.45->0.50mm — IPC Class 2 annular ring
    kicad-happy DFM-002: 0.45/0.25 via = 0.10mm annular, below IPC-6012
    Class 2 minimum 0.125mm. 0.50/0.25 = 0.125mm exactly. DRC stays 0 errors.
    [nova_pcb_v6_power_v2.kicad_pcb]
2026-06-12 pcb(v6-power-v2): backfill MPN + Manufacturer fields — 100% BOM coverage
    All 50 BOM components now carry MPNs from the verified order list:
    Yageo RC0603 resistor set (R14 470k = Vishay CRCW0603 DigiKey sub),
    Nichicon UPW1E bulk caps, Bourns SRR1260-220M, Infineon IRLB3034PBF,
    onsemi BSS138 x3, TI LM393DR, Pololu buck modules (off-board),
    GODIY INA226 20A R002 modules with I2C addresses in Manufacturer field,
    AMASS XT60H/XT30U, JST B3B-XH-A, Adam Tech BHR-12-VUA, Sullins headers.
    ERC: 0 errors (1 expected V7V5_ARM warning). kicad-happy bom_lock: pass.
    [01_battery.kicad_sch, 02_power_rails.kicad_sch, 03_servo_bus.kicad_sch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]
2026-06-12 pcb(v6-power-v2): correct C1-C5 to FymuSing (as purchased) + DigiKey PNs from order CSV
    Verified against Complete_Digikey_Order_NOVA.csv (16 lines, all match):
    R14 470k confirmed Vishay CRCW0603470KFKEA (541-470KHCT-ND).
    C1-C5 corrected Nichicon->FymuSing 1000uF/25V (Amazon purchase, 10x17mm).
    Remaining 23 parts without DigiKey PN are Amazon/Pololu/AMASS sourced.
    [01_battery.kicad_sch, 02_power_rails.kicad_sch, 03_servo_bus.kicad_sch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]
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2026-06-12 pcb(v6-power-v2): nudge C4 1.0mm inboard — edge clearance 0.3 -> 1.3mm
    kicad-happy PM-002 error cleared. Pads feed LEG pour / GND plane only,
    no tracks to move. Zones refilled, DRC 0 errors.
    [nova_pcb_v6_power_v2.kicad_pcb]
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2026-06-12 fix(firmware,nova_ops): close both safety gaps + boot-broadcast bug
    Firmware (teensy41_ci build green):
    - command-staleness failsafe: 500ms without /joint_commands -> freeze
    targets at measured positions (slew makes it gentle), /command_stale
    Bool edge topic, auto-recovery on fresh command
    - boot-broadcast gate: never SYNC_WRITE before first real command —
    previously slammed all 12 joints to raw 0 at 40Hz from power-on
    nova_ops (7 unit tests pass):
    - battery_shutdown_node (§10): /safety_state==2 fires immediately,
    raw /battery_low sustained 2s as backup; permanent once fired;
    /shutdown_imminent transient-local; grace for dashcam flush; then
    sudo -n systemctl poweroff. dry_run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
    [main.cpp]
2026-06-12 fix(firmware,nova_ops): adversarial review — 3 critical bugs
    1. 74HC125 OE polarity INVERTED (active-low part, firmware drove
    active-high): TX never drove the bus + UART idle fought servo
    responses through the TX gate during RX. Verified against logic-board
    netlist (U7 gate1 OE=OE_TX, gate2 OE=OE_RX, no inverters). Fixed
    set_tx/set_rx + all comments.
    2. SYNC_WRITE stack overflow: 12-servo frame = 44B into 38B stack
    buffer, smashed 6B at 40Hz. MAX_PARAM_BYTES 32->40 + frame-size
    guard independent of the n<=12 bound.
    3. Edge-only safety topics blinded late joiners (respawned
    battery_shutdown could never see an already-latched battery state).
    /estop /battery_low /safet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
    [feetech_bus.h, main.cpp]
2026-06-12 fix(firmware,nova_calibration): adversarial pass 2 — cold-boot brick + probe goal runaway
    1. Cold-boot brick: rclc_support_init RCCHECK'd into while(1) before
    the tick timer/watchdog started; Jetson (agent host) boots 30-60s
    after the Teensy, so every real power-up bricked the firmware until
    power cycle. Now retries forever with 2Hz LED blink — safe because
    broadcast is gated on first command and the safety chain is hardware.
    2. Hard-stop probe goal runaway: open-loop goal advance ground gears
    against compliant printed stops below the load threshold. Goal now
    leashed to 24 raw past last measured position; bounded torque,
    compliant stops resolve as TIMEOUT. +2 regress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
    [main.cpp]
2026-06-12 pcb(v6-power-v2): sync nova_v6 library footprints from board — 13->5 DRC mismatch warnings
    INA226_Module_Breakout: 12-pad module -> 4-pad I2C header landing
    (matches the off-board conversion; descr documents wiring + addresses).
    Buck_Offboard_Terminal_2xXT30: synced board geometry to lib.
    Remaining 5 warnings (J2 M1 Q1 SW1 SW2) = upstream KiCad 9 stock-lib
    drift since placement — cosmetic, deliberately NOT updated pre-fab
    (refreshing stock footprints can shift pads under routed copper).
    Gerbers never consult libraries; zero fab impact.
    [nova_pcb_v6_power_v2.kicad_pcb]
2026-06-12 pcb(v6-power-v2): BOARD COMPLETE — pour seams closed, GND orphans stitched, DRC 0/0
    - LEG pour islands bridged: 2.5mm F.Cu trunk crossing y67 west of the
    SDA fence (x109), no vias in the 9A path
    - GND orphan islands stitched to In1 plane: Q4 source + R16 pulldown
    (both were FLOATING — Jetson cutoff + gate-default-off would have
    shipped dead) + comb fragments; inter-pad slivers culled at 8mm²
    - DRC: 0 errors, 0 unconnected. Remaining warnings cosmetic only
    (5 stock-lib drift, 1 silk-over-copper).
    [nova_pcb_v6_power_v2.kicad_pcb]
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2026-06-13 fix(logic): un-DNP R1 (22R) + FB1 (ferrite) — series bus parts must be populated
    Bug found in 2026-06-13 review: BUS_SIGNAL(74HC125 out)->R1->FB1->BUS_SERVO
    runs through both parts IN SERIES with no bypass. DNP = open bus.
    Original §5 intent (optional tuning footprints, populate-if-noisy) was
    sound but they're load-bearing in the only path. Populate by default:
    R1=22R (source termination, reduces ringing — good regardless),
    FB1=ferrite (common-mode rejection). Tune values later if needed,
    never depopulate. ERC: no new violations (18 pre-existing logic-board
    in-progress items remain).
    [05_bus_integrity.kicad_sch]
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2026-06-14 fix(logic): +3V3 sourced from Teensy 3.3V (T3V3O pin added) — board-killer bug fixed
    Netlist verified: +3V3 = [U6.T3V3O(3V3), U7.10/13/14(VCC), J20.5]. 74HC125
    + 3x INA226 now powered. Combined with R1/FB1 un-DNP, both logic-board
    bugs from the 2026-06-13 review are resolved. Board left unrouted-clean
    for autorouting (Freerouting).
    [04_bus_master.kicad_sch, 07_aux_mcu.kicad_sch, 09_interboard.kicad_sch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]
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2026-06-14 pcb(logic): ROUTED via Freerouting — DRC 0 errors, 0 unconnected
    24 nets autorouted (154 tracks, 3 vias) on the +3V3/R1/FB1-fixed netlist.
    GND/V5_AUX inner planes filled. Min thermal spokes 2->1 to clear 4 GND
    starved-thermal on Freerouting-packed pads (1-spoke relief fine + eases
    hand-solder; pads also tie to inner GND plane). 7 cosmetic lib warnings.
    [nova_pcb_v6_logic.kicad_pcb]
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2026-06-14 pcb(logic): add C1 100nF decoupling at U7 + re-route — DRC 0/0 COMPLETE
    C1 (CC0603 100nF) across +3V3/GND placed next to U7 pin14; full board
    re-routed via Freerouting (25 nets, 159 tracks, 2 vias). DRC: 0 errors,
    0 unconnected. 7 cosmetic lib warnings. Logic board fab-ready.
    [04_bus_master.kicad_sch, nova_pcb_v6_logic.kicad_pcb]
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2026-06-14 logic board: add e-stop sense to Teensy + reconcile firmware pins to board
    Hardware e-stop (Q3) killed bucks autonomously but the Teensy was blind —
    no ESTOP line crossed J20 (all 12 pins used). Added direct sense so the
    SafetyFSM, /estop telemetry, and preflight can see e-stop state.
    Board (nova_pcb_v6_logic):
    - J21 (Conn_01x02) -> e-stop button 2nd NC dry contact -> Teensy pin 5
    (INPUT_PULLUP) + GND. NC-to-GND = LOW idle; pressed/break/unplug = HIGH
    = e-stop (fail-safe). Dry contact = no level-shift hazard.
    - Routed F.Cu J21.1->U6.T5; existing 154 tracks untouched. DRC 0/0.
    - Gerbers re-cut. No power-board / J20 change.
    Firmware (teensy41_ci green) - pin defines reconciled to board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
    [04_bus_master.kicad_sch, nova_pcb_v6_logic.kicad_pcb]
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

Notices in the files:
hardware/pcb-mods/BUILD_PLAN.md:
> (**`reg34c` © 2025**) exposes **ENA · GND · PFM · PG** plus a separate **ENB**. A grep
